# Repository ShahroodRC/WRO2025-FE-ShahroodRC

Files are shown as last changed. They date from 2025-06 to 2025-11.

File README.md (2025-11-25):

<!------------------------------------------------------------------->
<!--                     ShahroodRC – WRO 2025                     -->
<!------------------------------------------------------------------->

<div align="center">

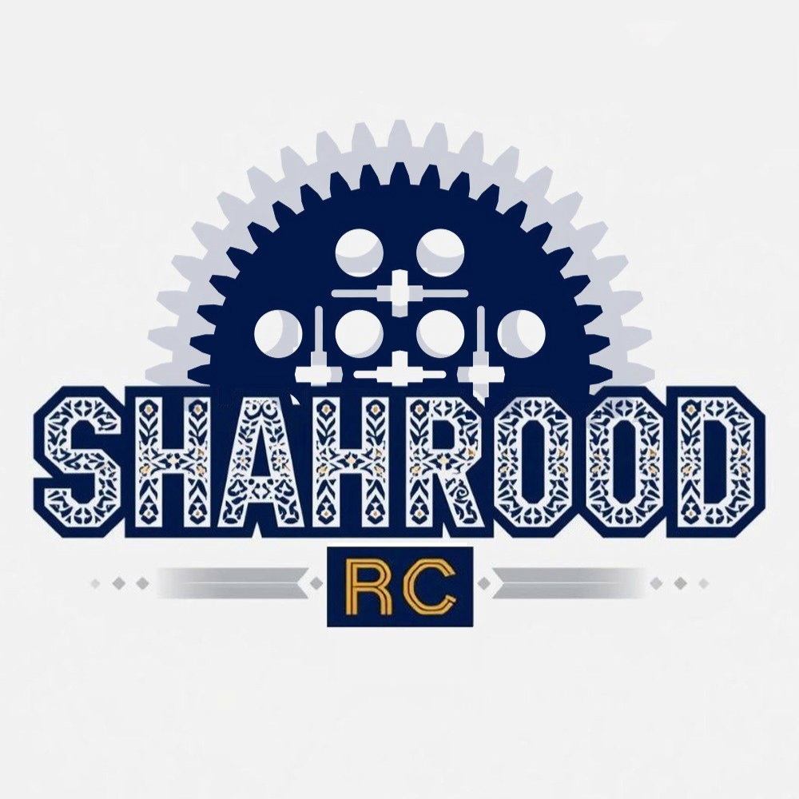
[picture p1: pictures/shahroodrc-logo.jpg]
ShahroodRC logo


**ShahroodRC** – *Future Engineers 2025*  
🏆 **1st Place – Iran National WRO 2025**  
🌍 **Heading to Singapore International Final (26-28 Nov 2025)**  
A fully autonomous LEGO EV3 robot with vision-based obstacle avoidance and precision navigation.





**📱 Connect with us:**




</div>

---

## 🎯 Key Features
| Feature | Details |
|---|---|
| 🤖 **Platform** | LEGO EV3 Mindstorms with Python (ev3dev) |
| 👁️ **Vision System** | Pixy 2.1 camera (60 fps, real-time obstacle detection) |
| 🧭 **Navigation** | Dual ultrasonic sensors + color sensor for precision wall-following |
| ⚡ **Performance** | 90% success rate in 50+ test runs; completes challenges in <2min |
| 🔧 **Custom Parts** | 3D-printed Pixy 2.1 mount for optimal positioning |
| 📦 **Components** | All standard LEGO pieces (100% WRO-compliant) |

---

## The Meaning Behind ShahroodRC

ShahroodRC blends "Shahrood" (our hometown in Iran, symbolizing resilience like its mountains) with "RC" (Robotics Club). Inspired by the story of iteration, teamwork, and turning "what if" into "we did it." Behind the code and gears? The quiet support of families – our real "power source," fueling late nights and breakthroughs. ShahroodRC isn't just a robot; it's proof that passion and persistence lead to a global stage.

---

## Table of Contents

- [👥 The Team](#-the-team)
- [🏆 National Championship Victory](#-national-championship-victory)
- [🎯 Mission Overview for WRO Future Engineers Rounds](#-mission-overview-for-wro-future-engineers-rounds)
- [📸 Pictures](#-pictures)
- [🎬 Videos](#-videos)
- [📱 Randomizer App](#-randomizer-app)
- [🔄 Our Path – Platform Evolution](#-our-path--platform-evolution)
    - [🔁 1. Using Arduino Uno](#-1-using-arduino-uno)
    - [🔁 2. Switching to ESP32](#-2-switching-to-esp32)
    - [🔁 3. Adopting Raspberry Pi Zero](#-3-adopting-raspberry-pi-zero)
    - [✅ 4. Final Transition to LEGO EV3](#-4-final-transition-to-lego-ev3)
    - [📊 Platform Comparison](#-platform-comparison)
    - [📌 Final Summary & Reflection](#-final-summary--reflection)
- [🔄 Design Evolution & Iteration History](#-design-evolution--iteration-history)
- [📊 Performance Metrics & Statistics](#-performance-metrics--statistics)
- [🤖 Robot Components Overview](#-robot-components-overview)
    - [📐 Dimensions](#-dimensions)
    - [🔧 Components Overview](#-components-overview)
        - [🧠 LEGO EV3 Mindstorms Control Brick](#-lego-ev3-mindstorms-control-brick)
        - [👁️ Pixy 2.1](#️-pixy-21)
        - [📏 Ultrasonic Sensor EV3](#-ultrasonic-sensor-ev3)
        - [🌈 Color Sensor EV3](#-color-sensor-ev3)
        - [⚙️ Medium Motor EV3](#️-medium-motor-ev3)
    - [🔌 EV3 Motor Cable & Port Architecture](#-ev3-motor-cable--port-architecture)
    - [🛠️ Notes](#️-notes)
- [💻 Code For Each Component](#-code-for-each-component)
    - [🔄 Drive Motor Code](#-drive-motor-code)
    - [🎯 Steering Motor Code](#-steering-motor-code)
    - [📷 Pixy Camera Code](#-pixy-camera-code)
    - [🌈 Color Sensor Code](#-color-sensor-code)
    - [💡 LED Indicator Code](#-led-indicator-code)
    - [📏 Ultrasonic Sensor Code](#-ultrasonic-sensor-code)
    - [🔘 Button Control Code](#-button-control-code)
    - [⚡ Main Control Flow](#-main-control-flow)
- [🚗 Mobility Management](#-mobility-management)
    - [1. 📍 Introduction to Mobility System](#1--introduction-to-mobility-system)
    - [2. ⚙️ Motors and Actuators](#2-️-motors-and-actuators)
        - [⚙️ Powertrain & Gear System (Gears and Differential)](#️-powertrain--gear-system-gears-and-differential)
        - [🔧 Differential Modification: Half-Bush Integration](#-differential-modification-half-bush-integration)
    - [3. 📡 Sensor Integration for Mobility](#3--sensor-integration-for-mobility)
    - [4. 🎮 Mobility Control Algorithms](#4--mobility-control-algorithms)
        - [Non-Linear Control for Initial Alignment](#non-linear-control-for-initial-alignment)
        - [Linear Control for Sustained Navigation](#linear-control-for-sustained-navigation)
    - [5. ⚡ Energy Management for Mobility](#5--energy-management-for-mobility)
    - [6. 🔗 System Integration for Mobility](#6--system-integration-for-mobility)
    - [7. 🧪 Testing and Optimization](#7--testing-and-optimization)
    - [8. ✅ Conclusion](#8--conclusion)
- [⚡ Power and Sense Management](#-power-and-sense-management)
    - [1. 🔋 Power Supply and Distribution](#1--power-supply-and-distribution)
        - [Hardware Specifications & Electrical Diagram](#hardware-specifications--electrical-diagram)
    - [2. 📊 Power Consumption Overview](#2--power-consumption-overview)
    - [3. 📡 Sensor Architecture and Management](#3--sensor-architecture-and-management)
    - [4. 🔗 Wiring and Safety](#4--wiring-and-safety)
        - [🌬️ Cooling System: Fan for Thermal Management](#️-cooling-system-fan-for-thermal-management)    
        - [💡 Advanced Application: EV3 Motor Port for External LED Control](#-advanced-application-ev3-motor-port-for-external-led-control)
    - [5. 🔍 Diagnostics and Monitoring](#5--diagnostics-and-monitoring)
    - [6. ⚙️ Optimization Techniques](#6-️-optimization-techniques)
    - [7. ✅ Conclusion](#7--conclusion)
- [🚧 Obstacle Management](#-obstacle-management)
    - [🏁 Qualification Round (Open Challenge)](#-qualification-round-open-challenge)
    - [🏆 Final Round with Obstacle Avoidance (Obstacle Challenge)](#-final-round-with-obstacle-avoidance-obstacle-challenge)
- [🏗️ Robot Assembly Guide](#️-robot-assembly-guide)
- [🛠️ Software Setup & Installation](#️-software-setup--installation)
    - [📋 Prerequisites](#-prerequisites)
    - [💾 Step 1: Install ev3dev on the EV3 Brick](#-step-1-install-ev3dev-on-the-ev3-brick)
    - [🔌 Step 2: Connect to EV3 Brick](#-step-2-connect-to-ev3-brick)
    - [📦 Step 3: Install Required Python Libraries](#-step-3-install-required-python-libraries)
    - [⬇️ Step 4: Clone and Deploy Code](#️-step-4-clone-and-deploy-code)
    - [▶️ Step 5: Run Code on EV3](#️-step-5-run-code-on-ev3)
    - [🐛 Step 6: Debugging & Troubleshooting](#-step-6-debugging--troubleshooting)
    - [⌨️ Useful Commands](#️-useful-commands)
- [🔧 Sensor Calibration Guide](#-sensor-calibration-guide)
    - [📷 Pixy 2.1 Camera Calibration](#-pixy-21-camera-calibration)
    - [📏 Ultrasonic Sensor Calibration](#-ultrasonic-sensor-calibration)
    - [🌈 Color Sensor Calibration](#-color-sensor-calibration)
    - [✅ Pre-Competition Checklist](#-pre-competition-checklist)
- [🔴 Problems and Solutions](#-problems-and-solutions)
- [💰 Cost Report](#-cost-report)
- [📁 Repository Structure](#-repository-structure)
- [🤝 Contributing & Support](#-contributing--support)
- [📖 License](#-license)

---

## 👥 The Team

We are the ShahroodRC team, a group of dedicated students from Iran with a passion for robotics, electronics, and programming. Our goal is to design an innovative robot for the WRO 2025 Future Engineers category, leveraging technical skills and collaboration to tackle complex challenges.

### 👨‍💼 Sepehr Yavarzadeh
- **Role**: Project Manager and Software Engineer.
- **Age**: 16
- **Description**: Hey! I'm Sepehr, and this is my third WRO season. Last year, I won third place in our national competition in the Robo Mission category. This year I wanted to have a new experience. I'm interested in playing the piano and playing tennis. I'm passionate about programming, physics, and math.  
- sepehryavarzadeh@gmail.com
- [Github](https://github.com/Sepehryy)
- [Instagram](https://www.instagram.com/sepehr.yavarzadeh/)
- [Linkedin](https://www.linkedin.com/in/sepehr-yavarzadeh-9643252a3/)

<div align="center">
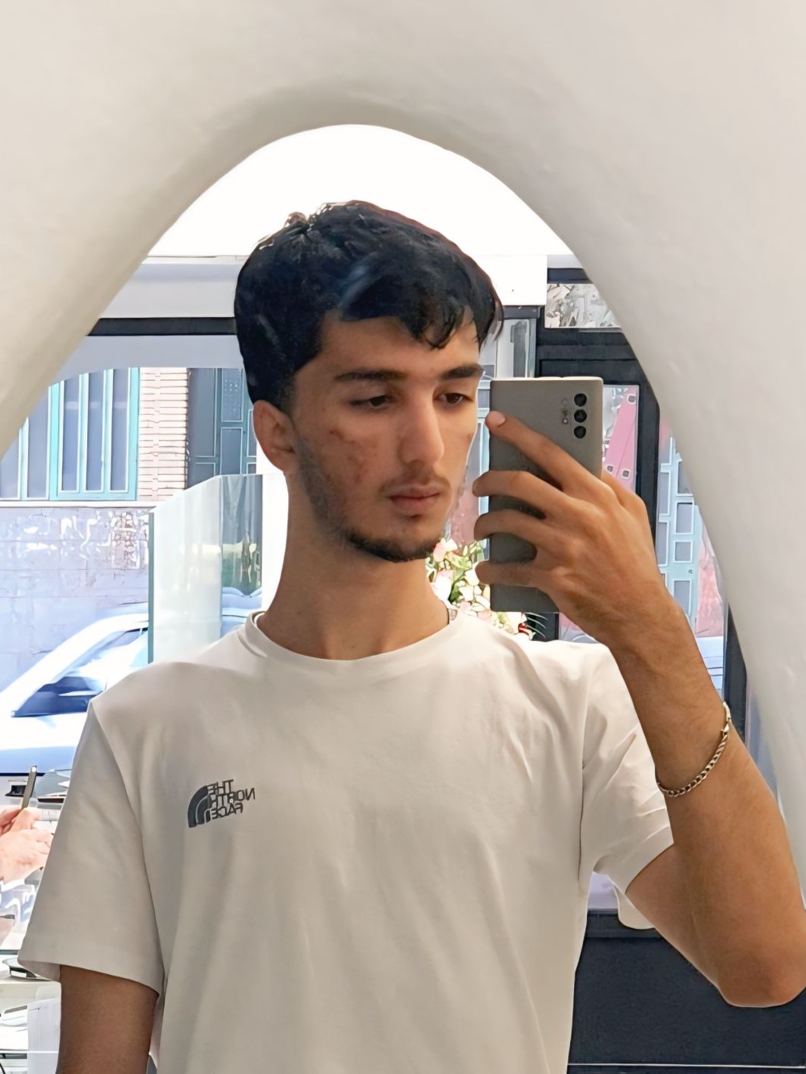
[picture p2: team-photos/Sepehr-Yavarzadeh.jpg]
Sepehr Yavarzadeh
 
<p>Sepehr Yavarzadeh</p>
</div>

---

### 👨🏼‍🔧 Nikan Bashiri
- **Role**: Mechanical and Electronics Specialist.
- **Age**: 17
- **Description**: Hi everyone! I'm Nikan from Iran. I'm an advanced LEGO robotics instructor at a training center, with experience participating in 5 WRO national finals. My expertise focuses on mechanical/electronic systems, as well as LEGO set design.  
- nikanbsr@gmail.com
- [Instagram](https://www.instagram.com/nikanbsr/)

<div align="center">
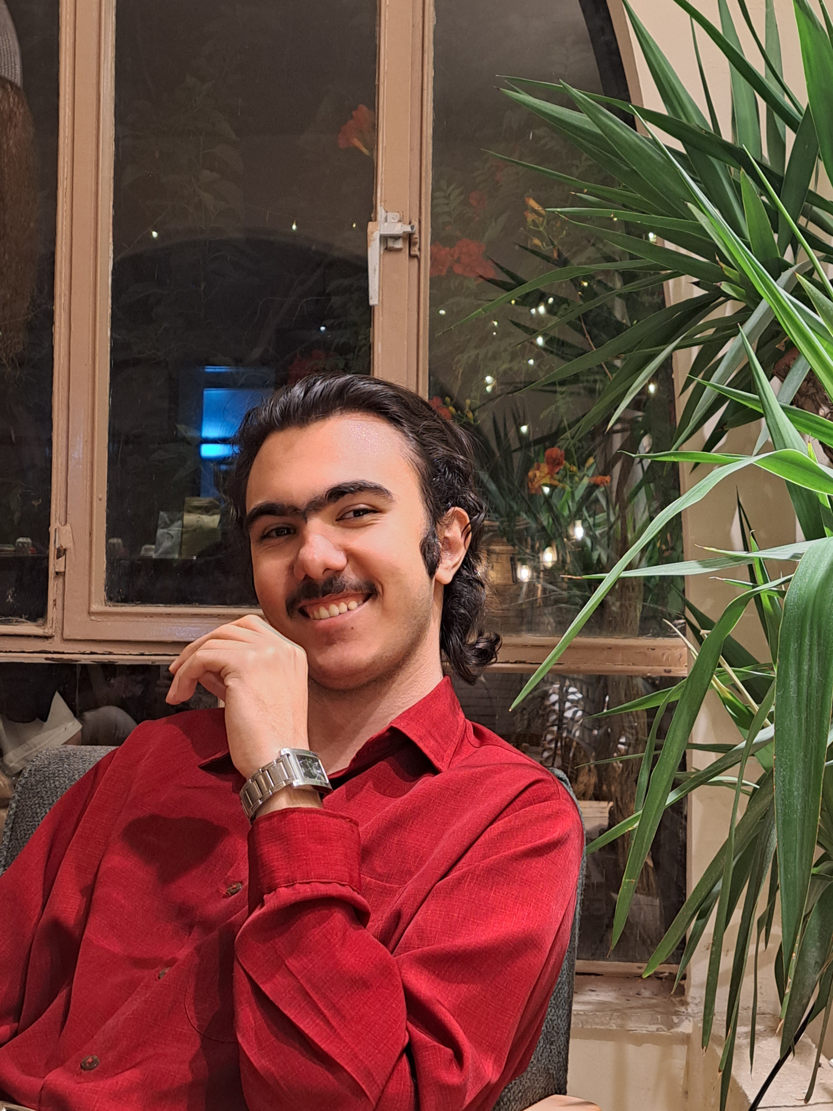
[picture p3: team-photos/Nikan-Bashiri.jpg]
Nikan Bashiri
 
<p>Nikan Bashiri</p>
</div>

---

### 🧑‍💻 Amirparsa Saemi
- **Role**: Lead Developer and Algorithm Designer.
- **Age**: 19
- **Description**: Hey! I'm Amirparsa, and this is my third year competing in WRO. I'm a professional ping-pong player and super passionate about math and physics. I'm studying computer science at university and love diving into programming challenges.
- amirparsa.saemi2021@gmail.com
- [Instagram](https://www.instagram.com/hotaru_tempest/)

<div align="center">
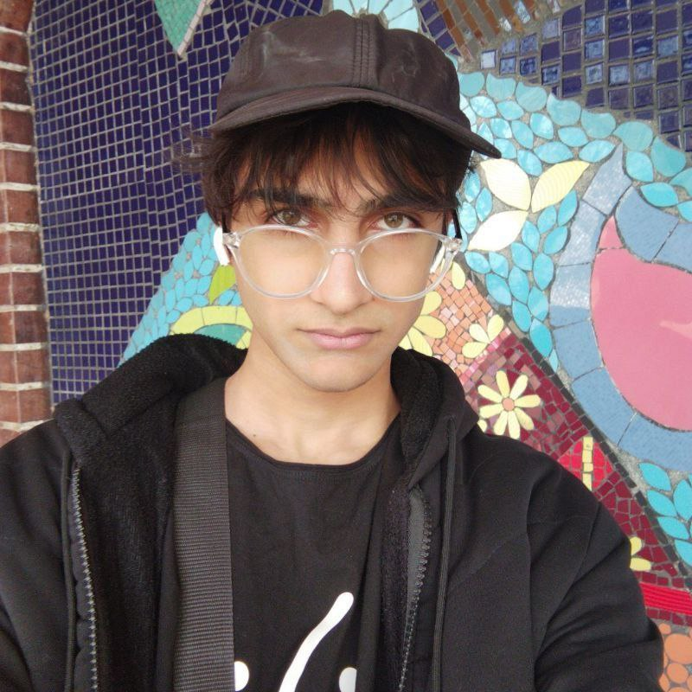
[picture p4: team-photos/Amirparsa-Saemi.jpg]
Amirparsa Saemi
 
<p>Amirparsa Saemi</p>
</div>

---

### 👨🏻‍🏫 Ali Raeesian
- **Role**: Coach
- **Age**: 24
- **Description**: Ali Raeisian, a B.Sc. graduate in Computer Engineering, is currently pursuing a Master’s degree in Computer Science with a focus on software. A former WRO competitor, he participated in the 2016 WRO global competition in India in the robot soccer category. Now, he specializes in game development, contributing his expertise to both technical and creative aspects of the field.
- raeesianali@gmail.com
- [Github](https://github.com/SheykhAlii)
- [Instagram](https://www.instagram.com/ali_raeesiian/)

<div align="center">
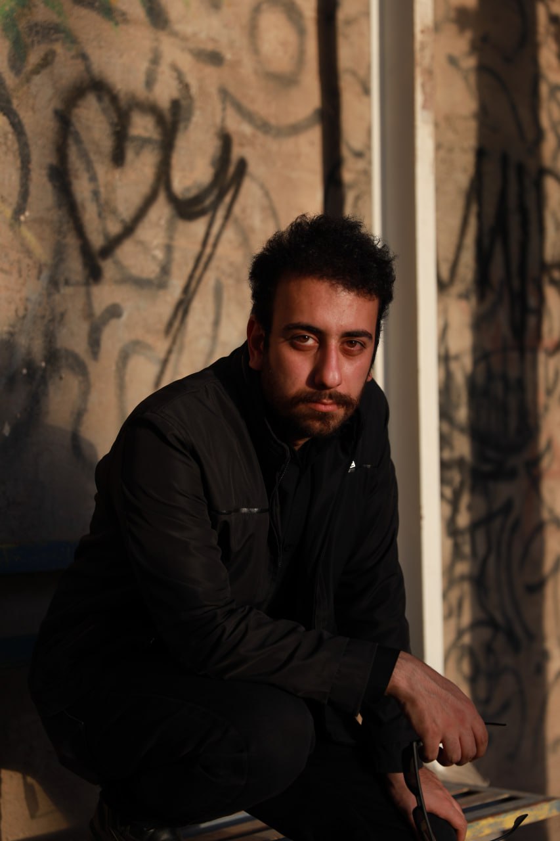
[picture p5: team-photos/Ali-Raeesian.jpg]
Ali Raeesian
 
<p>Ali Raeesian</p>
</div>

---

### 👨🏻‍🏫 Hossein Bagheri
- **Role**: Manager
- **Age**: 50
- **Description**: He is the founder of Shahrood's educational Lego institute. 
- [Instagram](https://www.instagram.com/ho.bagheri/)

<div align="center">
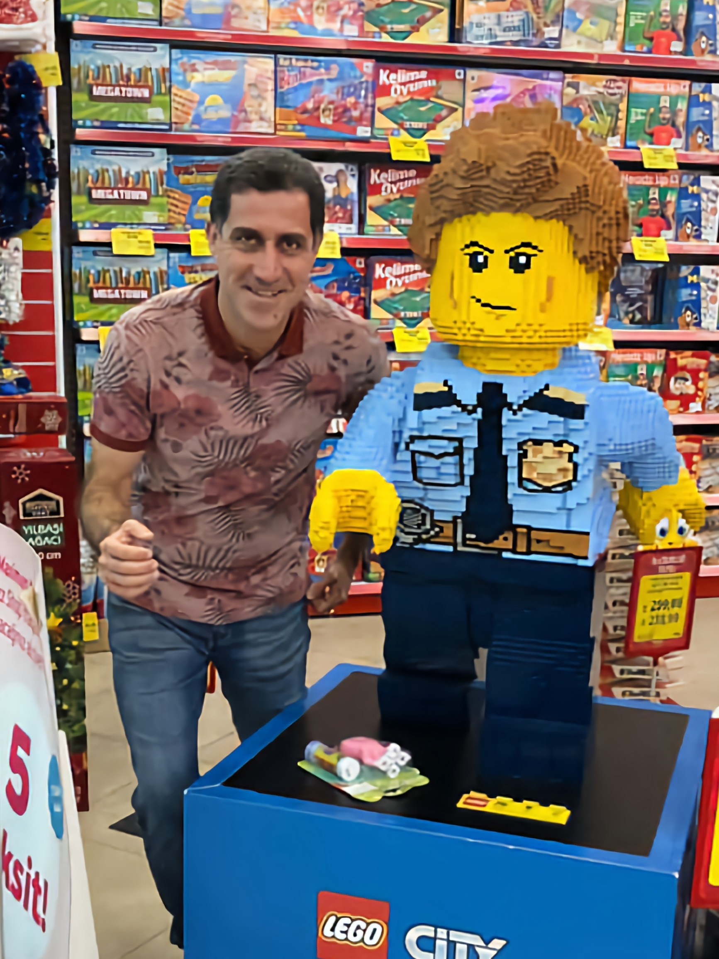
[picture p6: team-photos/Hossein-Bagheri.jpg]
Hossein Bagheri
 
<p>Hossein Bagheri</p>
</div>

---

### ShahroodRC Team
<div align="center">
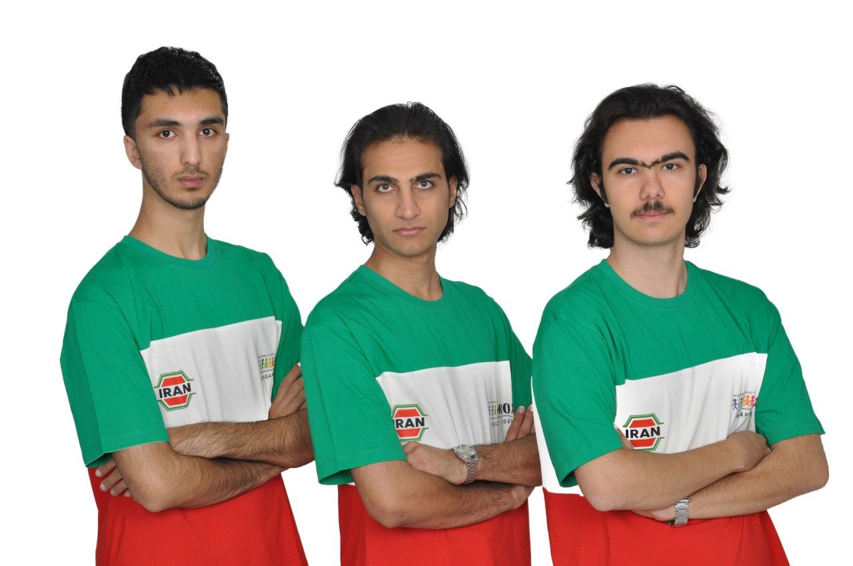
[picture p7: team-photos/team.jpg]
ShahroodRC
 
<p>The ShahroodRC Team</p>
</div>

<div align="center">
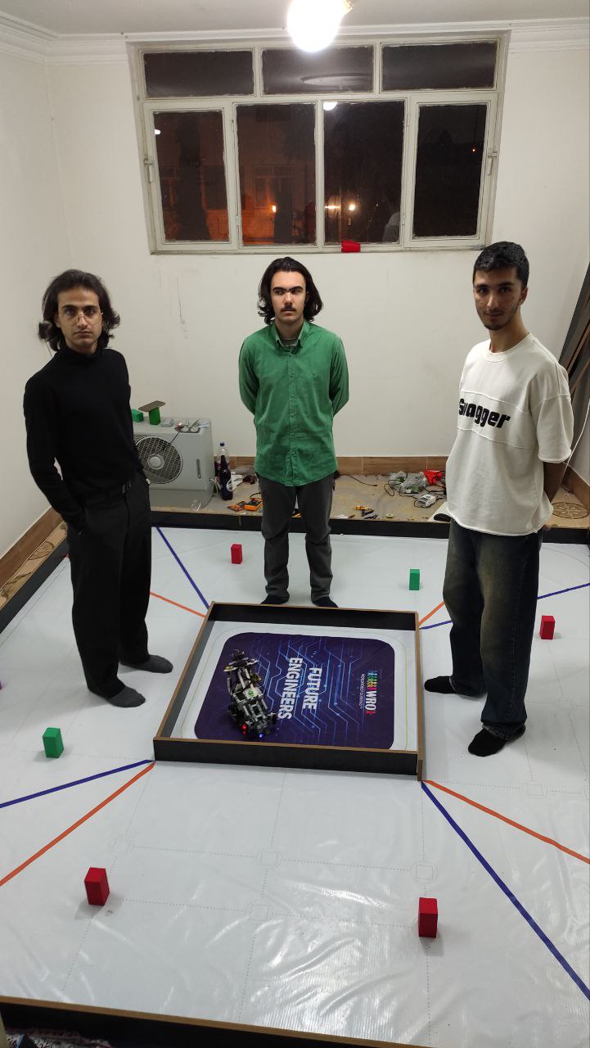
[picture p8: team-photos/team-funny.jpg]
Fun Team Moment
 
<p>Fun Team Moments 🎉</p>
</div>

> In this project, we aimed to combine creativity, teamwork, and technical knowledge to build an efficient robot for the challenges of WRO 2025.

---

## 🏆 National Championship Victory

### Overview
The ShahroodRC team achieved a impressive victory by securing **first place** in the **National WRO Competition**, the official qualifying event for the World Robot Olympiad (WRO) 2025 in the Future Engineers category. Held in **August 2025** in **Rasht, Iran**, this success highlighted our team’s dedication, teamwork, and innovative approach. Competing against many talented teams, we excelled in navigating challenging tracks, earning our qualification for the WRO 2025 International Final in Singapore (26–28 November 2025).

### Competition Highlights
- **Event**: Iran National Robotics Competition (WRO 2025 Qualifier)
- **Date**: August 2025
- **Location**: Rasht, Iran
- **Achievement**: 1st Place, qualifying for WRO 2025 International Final
- **Key Moment**: Our robot completed both the Open and Obstacle Challenges, demonstrating precision and reliability under competitive pressure.

### Visuals
<div align="center">
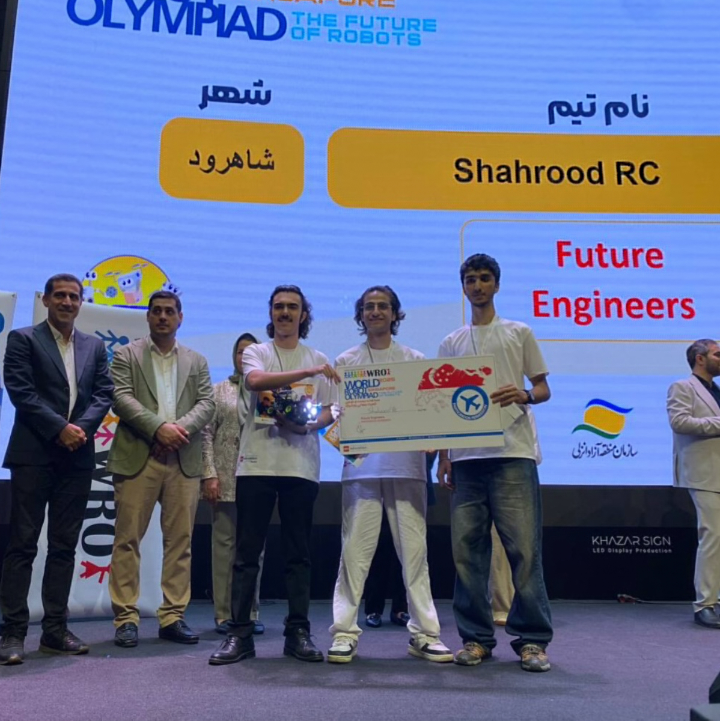
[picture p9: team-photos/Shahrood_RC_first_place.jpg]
ShahroodRC Team championship

<p>ShahroodRC’s championship victory at the National WRO Competition</p>
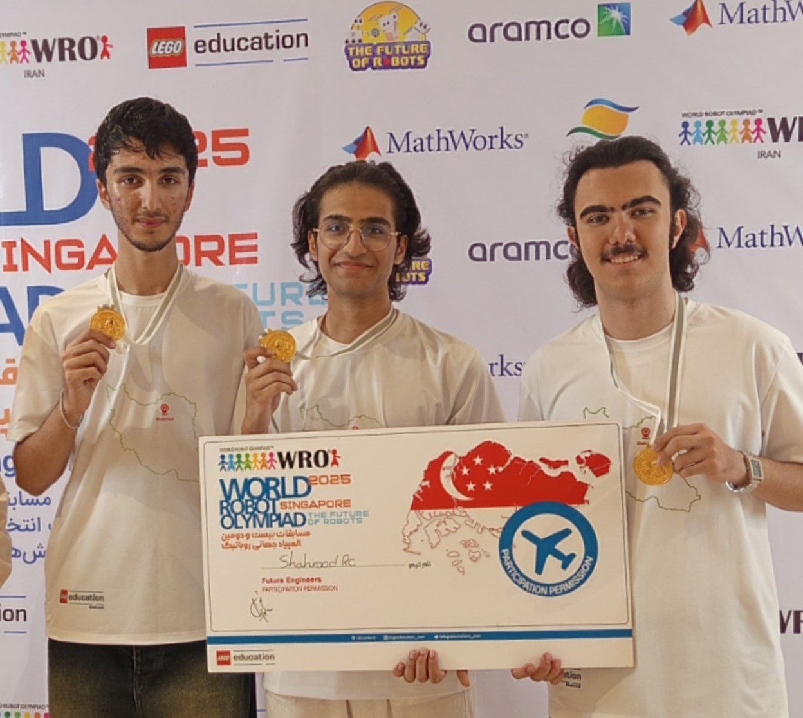
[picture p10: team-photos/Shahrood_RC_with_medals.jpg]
ShahroodRC Team with Award

<p>ShahroodRC Team celebrating their 1st Place victory</p>
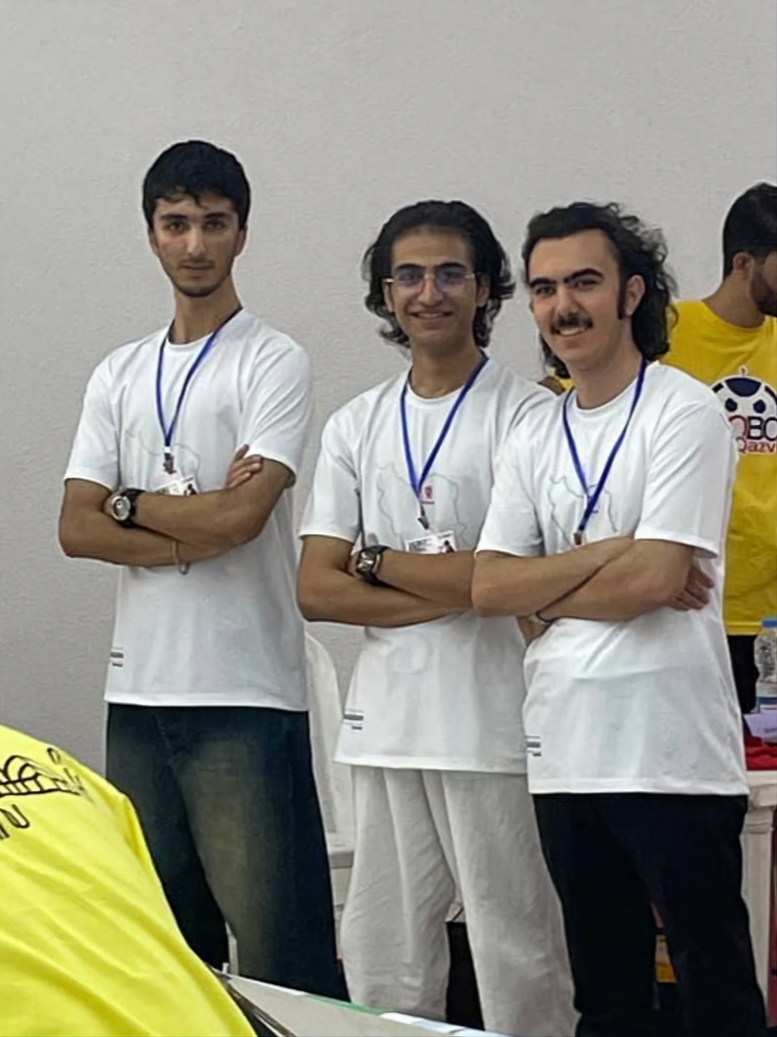
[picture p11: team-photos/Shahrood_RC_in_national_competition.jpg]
ShahroodRC Team in national competition

<p>ShahroodRC Team in National Final</p>
</div>
<div align="center">
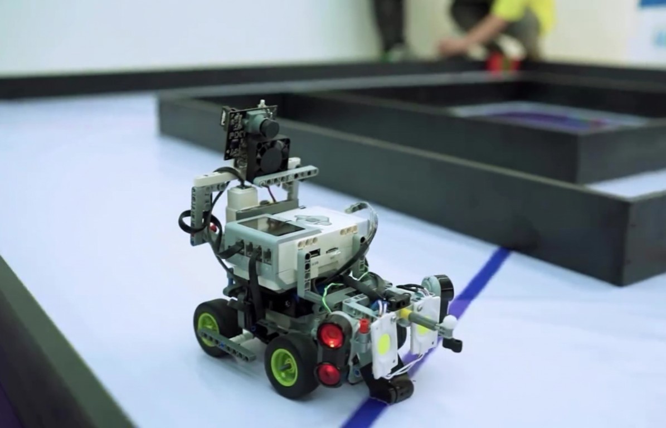
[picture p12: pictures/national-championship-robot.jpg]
Robot in Action

<p>Our robot in action during the National Championship</p>
</div>

### Path to WRO 2025
This national championship victory marks a significant milestone, qualifying ShahroodRC for the WRO 2025 International Final in Singapore. With the theme "The Future of Robots," we are ready to compete on the global stage, representing Iran with pride and showcasing our skills against over 500 international teams.

---

## 🎯 Mission Overview for WRO Future Engineers Rounds

<table>
  <tr>
    <td width="50%" valign="top" align="left">
      <h3>🏁 Qualification Round: Open Challenge</h3>
      <p>The robot must complete laps on a track without obstacles, demonstrating precision in wall-following and line detection.</p>
      <ul><li><strong>Goal</strong>: 3 laps, no obstacles.</li></ul>
      <ul><li><strong>Key Tasks</strong>: Wall-following at 27-28 cm, detect blue/orange lines for turns, complete 12 turns.</li></ul>
    </td>
    <td width="50%" valign="top" align="left">
      <h3>🏆 Final Round: Obstacle Challenge</h3>
      <p>Robot completes laps while avoiding green (left) and red (right) pillars, then parks in the designated zone.</p>
      <ul><li><strong>Goal</strong>: 3 laps + parking.</li></ul>
      <ul><li><strong>Key Tasks</strong>: Obstacle detection with Pixy, dynamic distance (40-55 cm), and precise parking.</li></ul>
    </td>
  </tr>
  <tr>
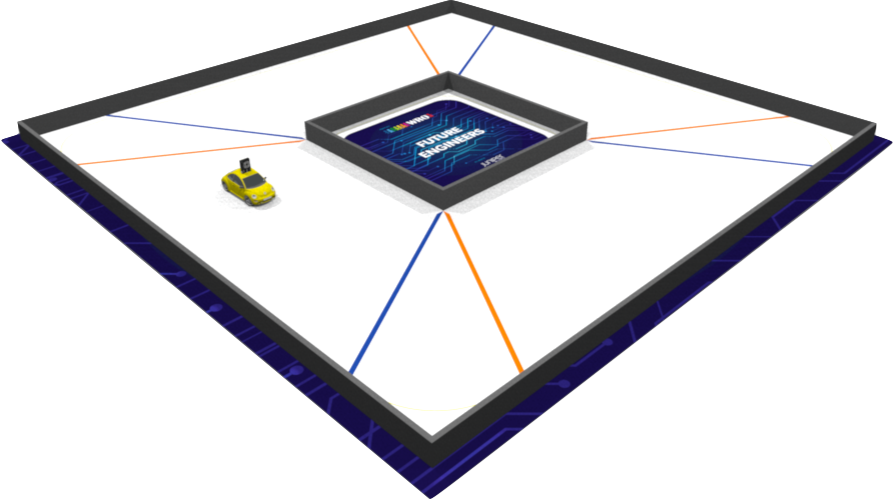
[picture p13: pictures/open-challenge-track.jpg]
    <td align="center"></td>
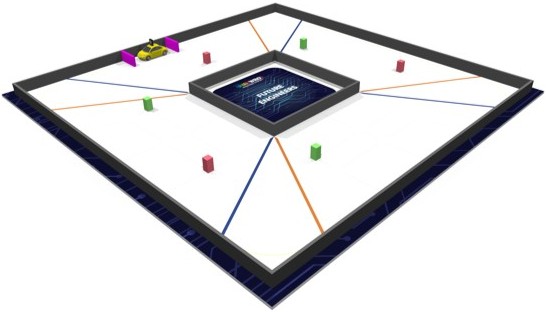
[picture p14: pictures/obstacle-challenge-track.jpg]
    <td align="center"></td>
  </tr>
</table>

> [!IMPORTANT]
> **WRO Future Engineers Rulebook**: Thoroughly read the rulebook for all guidelines. Official link: [WRO Future Engineers 2025 Rulebook](WRO-2025-Future-Engineers-Self-Driving-Cars-General-Rules.pdf). Key rules: Open – no obstacles, 3 laps; Obstacle – avoid pillars, park after laps.

---

## 📸 Pictures

| Front | Back |
|:-----:|:----:|
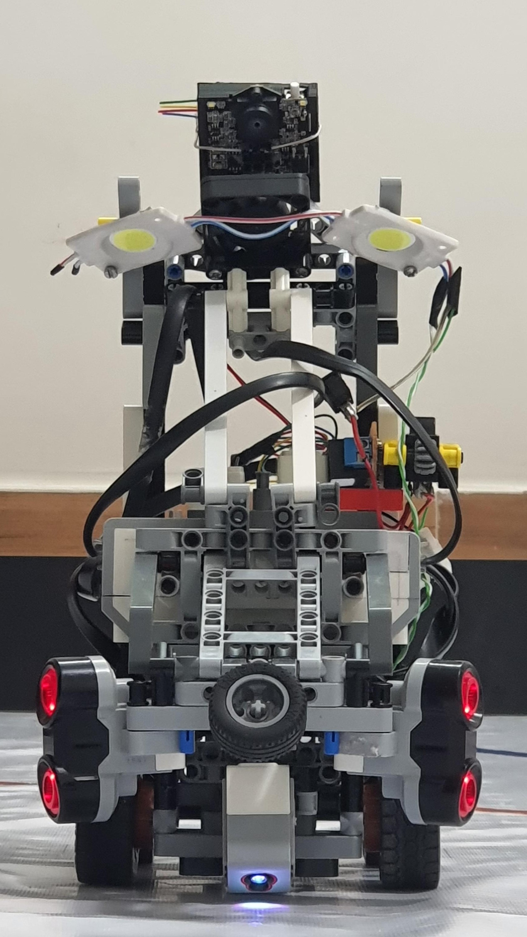
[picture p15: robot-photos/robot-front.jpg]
Front View
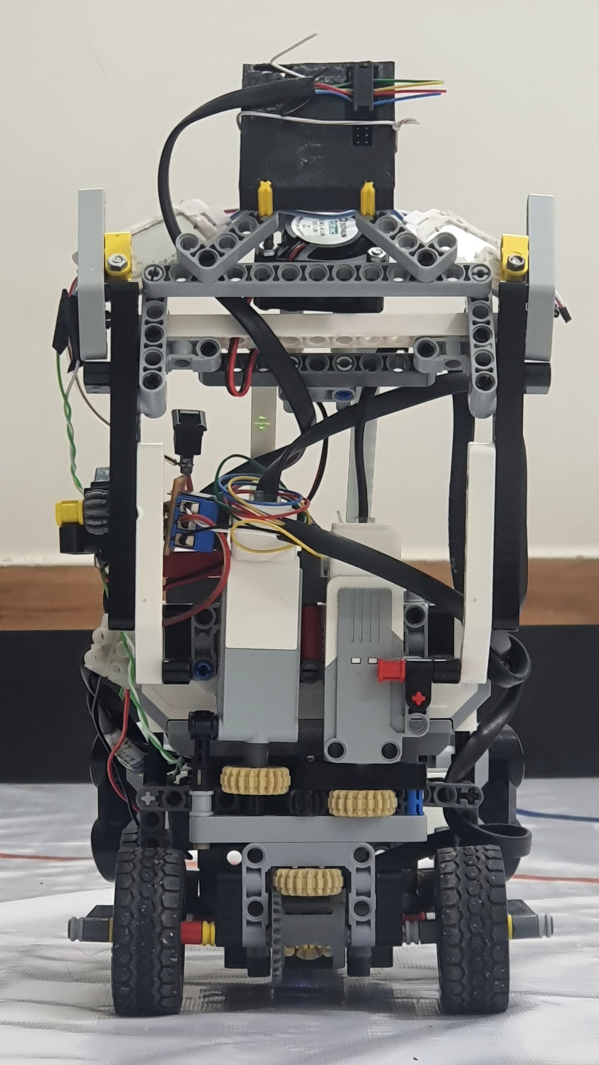
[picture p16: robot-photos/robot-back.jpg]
Back View
|  |  |

| Left | Right |
|:----:|:-----:|
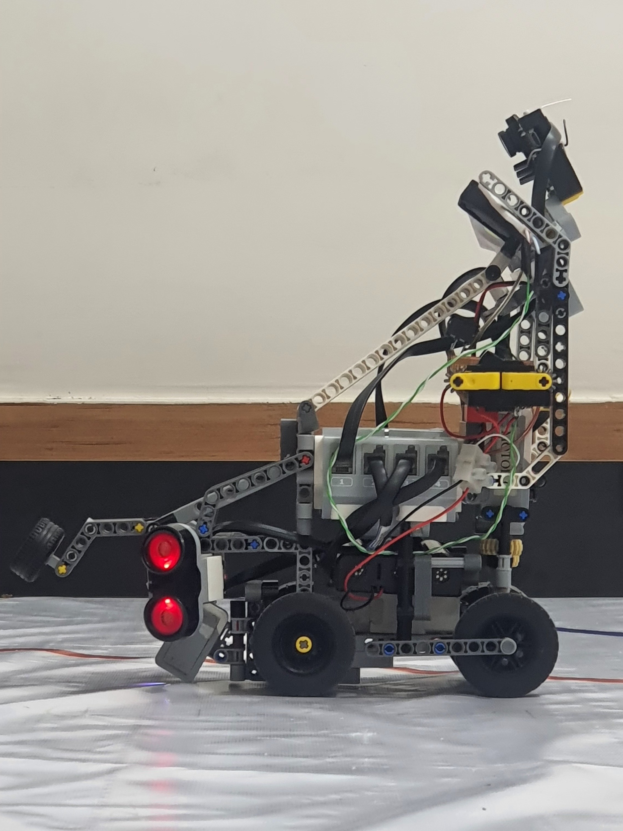
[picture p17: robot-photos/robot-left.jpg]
Left View
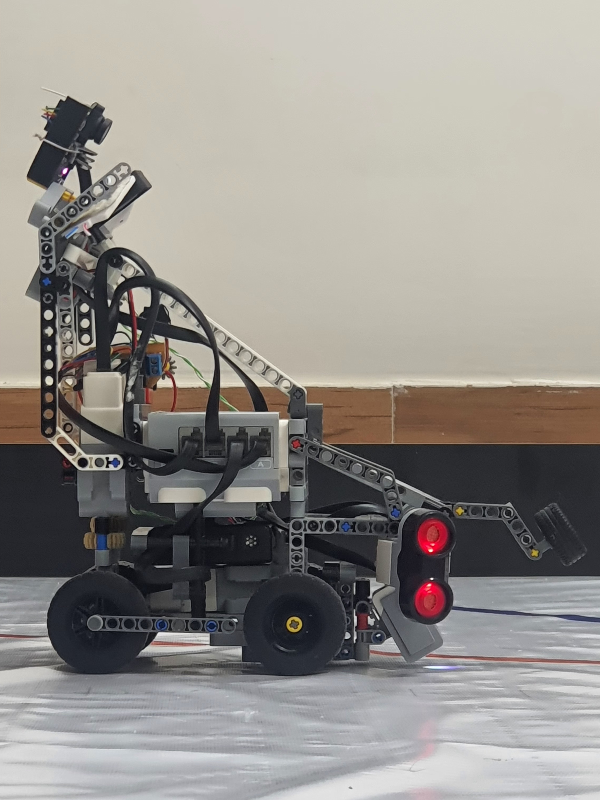
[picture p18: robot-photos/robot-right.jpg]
Right View
|  |  |

| Top | Bottom |
|:---:|:---:|
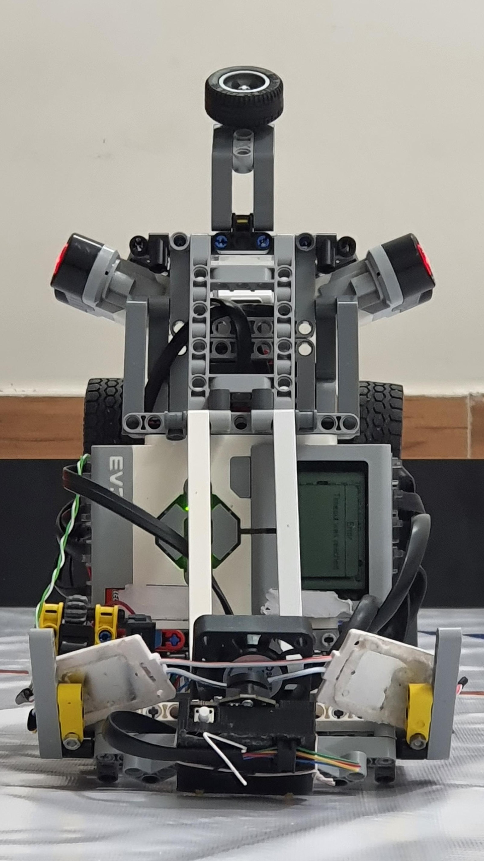
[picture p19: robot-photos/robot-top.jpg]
Top View
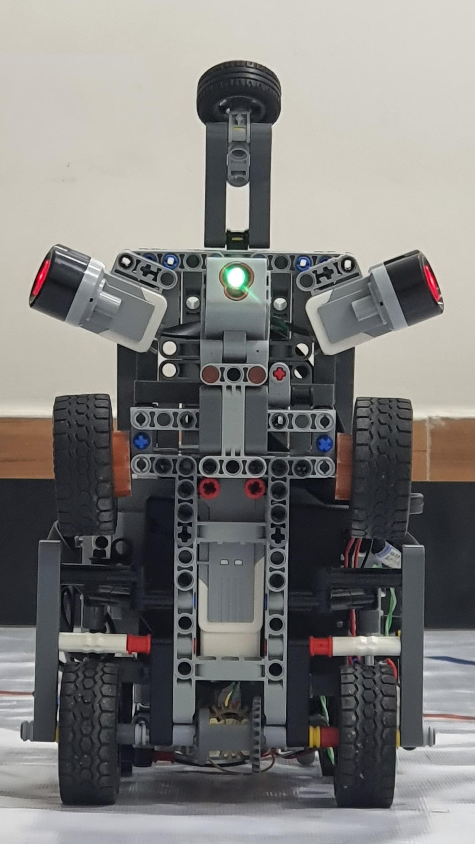
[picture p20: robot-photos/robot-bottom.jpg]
Bottom View
|  |  |

<div align="center">
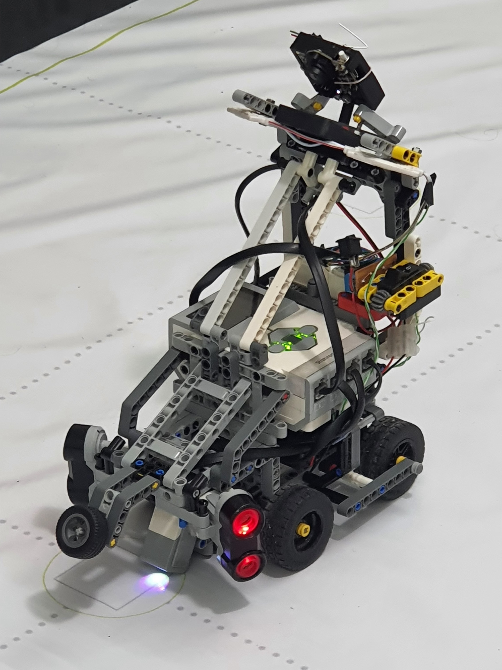
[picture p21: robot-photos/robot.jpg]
Three-Quarter View of the Robot
    
    <p>Three-Quarter View of the Robot (from front, left, and top)</p>
</div>

---

## 🎬 Videos

You can watch the [Obstacle Challenge](https://youtu.be/SnwjbTBg8ZY), [Open Challenge](https://youtu.be/YG6ZxuxHtCI), and [Explaining](https://youtu.be/0DZZhJmp3i8) videos on YouTube. You can also watch them here in the [videos](videos/) folder.

| Open Challenge | Obstacle Challenge | Explaining Video |
|---|---|---|
| Open (https://youtu.be/YG6ZxuxHtCI) | Obstacle (https://youtu.be/SnwjbTBg8ZY) | Explaining Video (https://youtu.be/0DZZhJmp3i8) |

---

## 📱 Randomizer App

> Generates **WRO-2025-compliant** random tracks for both challenges.

To assist teams and judges in simulating the dynamic and unpredictable nature of the WRO 2025 Future Engineers challenges, the ShahroodRC team developed a custom **Randomizer Application** for Android devices. This app generates randomized track layouts and obstacle configurations that comply with official WRO 2025 rules for both the **Open Challenge** and the **Obstacle Challenge**.

### App Screenshots
<div align="center">
  <table>
    <tr>
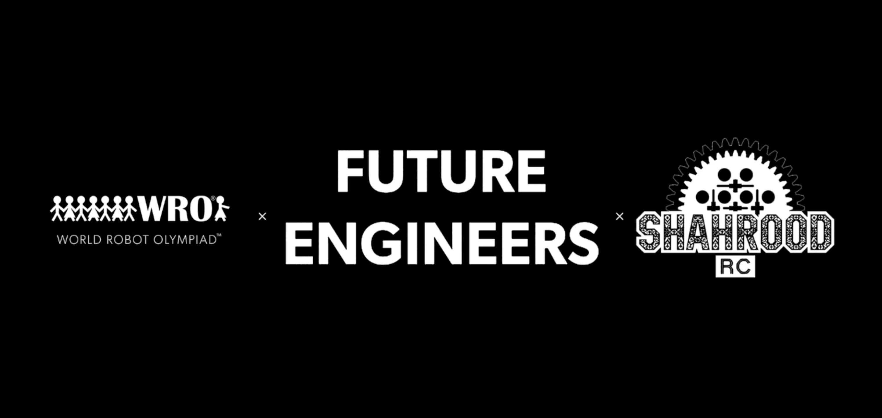
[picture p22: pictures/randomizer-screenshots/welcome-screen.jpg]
      <td></td>
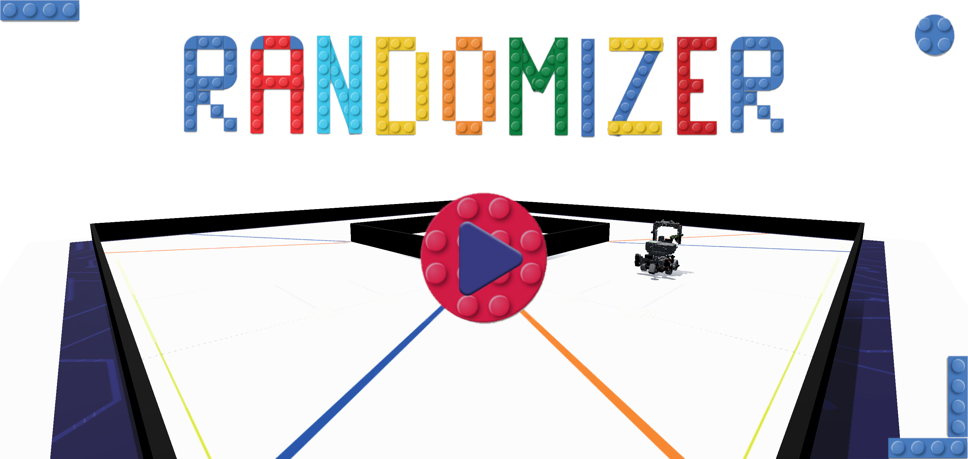
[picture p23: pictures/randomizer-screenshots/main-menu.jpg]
      <td></td>
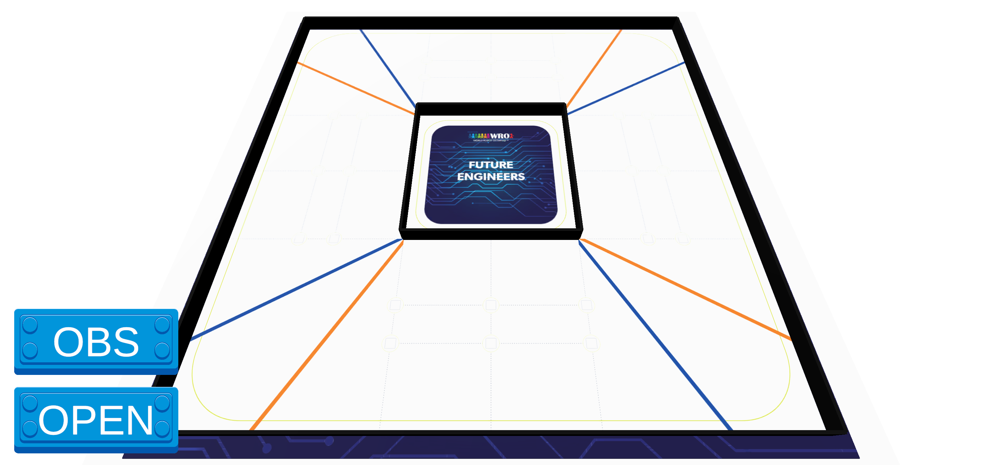
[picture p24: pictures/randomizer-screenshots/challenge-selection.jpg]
      <td></td>
    </tr>
    <tr>
      <td align="center"><b>Welcome Screen</b></td>
      <td align="center"><b>Main Menu</b></td>
      <td align="center"><b>Challenge Selection</b></td>
    </tr>
    <tr>
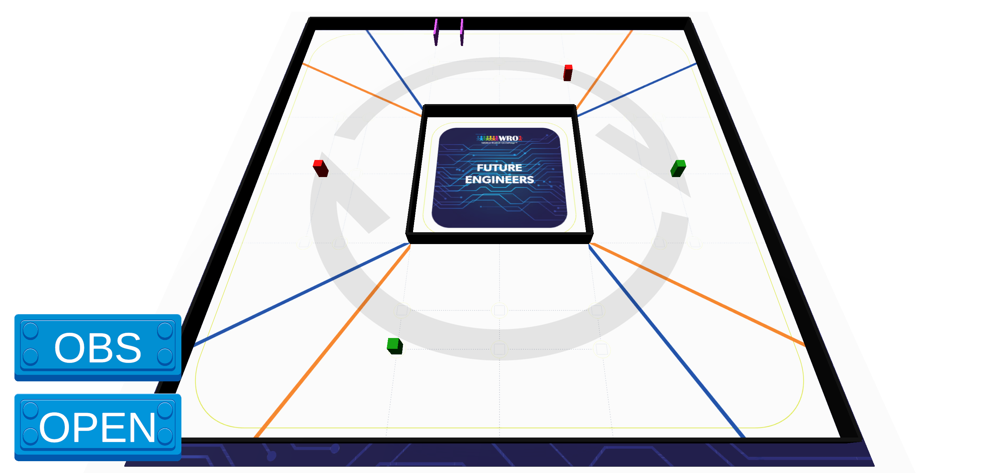
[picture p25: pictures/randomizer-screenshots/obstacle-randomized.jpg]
      <td></td>
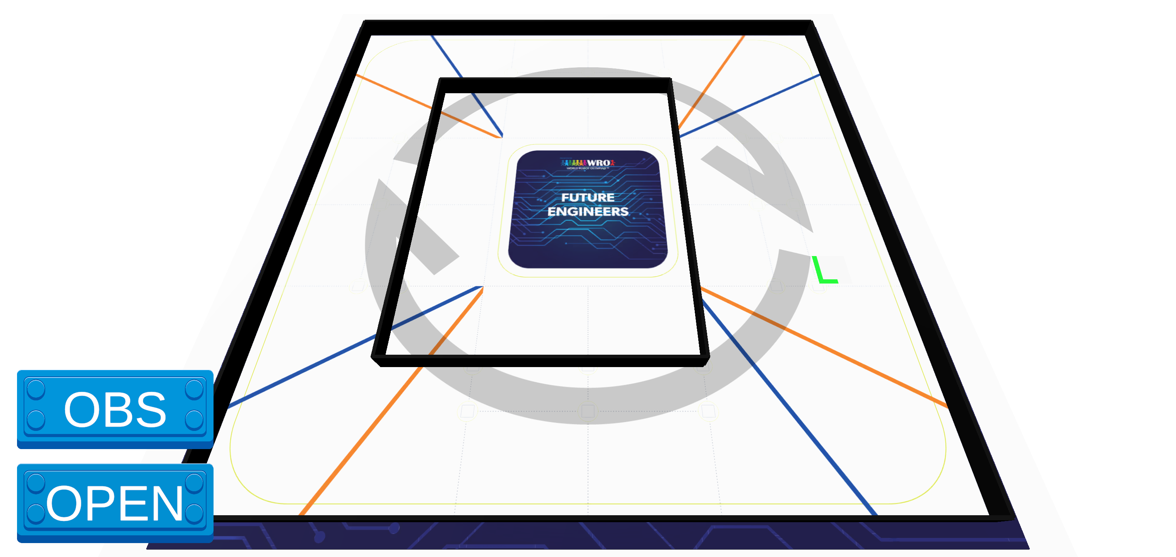
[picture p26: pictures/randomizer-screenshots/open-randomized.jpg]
      <td></td>
      <td></td>
    </tr>
    <tr>
      <td align="center"><b>Obstacle Challenge</b></td>
      <td align="center"><b>Open Challenge</b></td>
      <td></td>
    </tr>
  </table>
</div>

### Features
- **Dual Challenge Support**: Generates valid configurations for both Open and Obstacle rounds.
- **Rule-Compliant Outputs**: Ensures all generated layouts adhere to WRO 2025 regulations.
- **User-Friendly Interface**: Simple tap-to-generate design with clear visual feedback.
- **Offline Functionality**: No internet required—ideal for competition environments.
- **Export & Share**: Results can be viewed on-screen or shared as text.

### Usage
1. Install the APK file (`randomizer.apk`) on any Android device (min. Android 7.0 recommended).
2. Open the app and select your desired challenge type (**Open** or **Obs**) to receive a randomized, competition-ready layout.
3. Use the output to set up your practice arena or verify robot behavior.

> **Note**: This tool was used internally during our development and testing phases to ensure our robot could handle any valid WRO 2025 scenario with robustness and adaptability.

### Download
The latest version of the Randomizer app is included directly in this repository:
- [`randomizer.apk`](randomizer.apk)

> **Security Note**: This APK is built and signed by the ShahroodRC team. Always scan files with your preferred antivirus before installation.

---

## 🔄 Our Path – Platform Evolution

### Robot Development Process
The ShahroodRC team started a tough development process to find the most suitable, efficient, and reliable platform for our WRO 2025 Future Engineers robot. We tested multiple hardware platforms—Arduino Uno, ESP32, Raspberry Pi Zero, and LEGO EV3—evaluating each based on **processing power**, **sensor integration**, **power consumption**, **real-time performance**, and **reliability** in competition environments. Below is a detailed story of our journey, including the challenges faced and the lessons that guided us to our final platform choice.

---

### 🔁 1. Using Arduino Uno
We initially chose the **Arduino Uno** (ATmega328P, 16 MHz, 32 KB Flash, 2 KB SRAM) for its simplicity, affordability, and compatibility with a wide range of sensors and actuators. Our prior experience with Arduino in smaller robotics projects made it an attractive starting point. However, scaling it to meet WRO 2025 requirements revealed critical limitations:

- **Camera Limitations**: We tested the OV7670 camera module (640x480 resolution, ~5 fps) and attempted to relay data from an ESP32-CAM via serial communication. The Arduino’s limited SRAM (2 KB) and processing power couldn’t handle image processing, resulting in unreliable object detection and low frame rates, far below the ~30 fps needed for real-time obstacle avoidance.
- **Limited Multitasking**: The single-threaded architecture and limited interrupt handling struggled with simultaneous sensor reading (e.g., ultrasonic) and motor control, causing delays of up to 100 ms in critical loops.
- **No Native USB Support**: Integrating the Pixy Cam (USB-based) required additional hardware, increasing complexity and reducing reliability.

**Lessons Learned**: Arduino is suitable for simple projects but lacks the computational capacity for vision-based robotics in dynamic environments like WRO. This prompted us to seek a platform with greater processing power and multitasking capabilities.

---

### 🔁 2. Switching to ESP32
The **ESP32** (dual-core Xtensa LX6, 240 MHz, 520 KB SRAM) was our next choice, offering improved processing power, integrated Wi-Fi/Bluetooth, and better memory management. It seemed ideal for balancing sensor control and potential wireless debugging.

- **Pros**:
  - Dual-core processing enabled parallel tasks (e.g., sensor reading and motor control).
  - Wi-Fi/Bluetooth allowed for remote monitoring, useful during testing.
  - 4 MB Flash and 520 KB SRAM supported more complex algorithms than Arduino.
- **Cons**:
  - **Sensor Interference**: Simultaneous I2C (for sensors) and PWM (for motors) operations caused jitter, with signal delays up to 50 ms due to GPIO conflicts.
  - **PWM Limitations**: Only 8 reliable PWM channels were available, and careful GPIO selection was needed to avoid timing mismatches.
  - **Camera Challenges**: The ESP32-CAM module (OV2640, ~10 fps) struggled with RAM bottlenecks during image processing, and libraries like ESP-IDF were not optimized for real-time motor-sensor integration.
  - **Library Limitations**: MicroPython and Arduino ESP32 cores lacked robust image processing libraries for WRO’s dynamic requirements.

**Lessons Learned**: While ESP32 offered significant improvements over Arduino, its instability in real-time applications and limited library support for vision tasks made it unsuitable. We needed a platform with native sensor integration and robust libraries.

---

### 🔁 3. Adopting Raspberry Pi Zero
The **Raspberry Pi Zero** (1 GHz single-core ARM11, 512 MB RAM, Linux-based) was our next attempt, chosen for its support for Python, OpenCV, and USB add-ons like the Pixy Cam or Pi Camera.

- **Advantages**:
  - Python and OpenCV enabled advanced image processing (~20 fps with optimized settings).
  - Multi-threaded programming supported simultaneous sensor and motor tasks.
  - USB and I2C interfaces allowed easy integration of the Pixy Cam.
- **Challenges**:
  - **Power Sensitivity**: The Pi Zero required a stable 5V/2A supply. Voltage drops below 4.8V during motor and camera use caused sudden shutdowns.
  - **Heat Issues**: Continuous operation (camera streaming at 20 fps and motor control) raised board temperatures to ~65°C, leading to thermal throttling.
  - **Hardware Fragility**: We lost two boards—one due to a short circuit from an improperly grounded motor driver (TB6612FNG) drawing ~1.5A, and another from a current surge (~2A) when powering the camera and motors simultaneously.

**Lessons Learned**: The Pi Zero’s processing power was promising, but its fragility and power demands were impractical for competition use. We needed a more robust platform designed for educational robotics.

---

### ✅ 4. Final Transition to LEGO EV3
After facing challenges with previous platforms, we returned to the **LEGO EV3 Mindstorms** system (ARM9, 64 MB RAM, 16 MB Flash), leveraging our team’s prior WRO experience. The EV3 offered unmatched integration, safety, and reliability.

- **Stability & Robustness**: The EV3 Intelligent Brick is built for rugged environments, handling two Medium Motors (20 N·cm, 160 rpm) and four sensors without external drivers.
- **Built-in Ports**: Four motor ports and four sensor ports (e.g., INPUT_1 for the Pixy Cam, INPUT_2/3 for the Ultrasonic Sensors, INPUT_4 for the Color Sensor), simplified wiring, and reduced failure risks.
- **Pixy Cam Integration**: Using a custom I2C connection (via EV3 sensor port, 5V/120–160 mA), we integrated the Pixy Cam without USB host requirements, ensuring compatibility.
- **Development Efficiency**: Python via ev3dev allowed rapid development, with libraries like `ev3dev2` supporting precise motor control (e.g., `on_for_degrees`) and sensor polling (10 ms for color sensor).
- **Competition-Proven**: The EV3’s extensive use in WRO and availability of open-source libraries ensured reliable performance.

**Implementation Impact**: The EV3’s stability influenced our code design, enabling a PID-like steering algorithm (`amotor`) and dynamic distance adjustment (`fasele`) for robust navigation. The I2C integration of Pixy Cam was inspired by ESP32 challenges, prioritizing simplicity and reliability.

---

### 📊 Platform Comparison
| **Platform** | **Processing Power** | **Sensor Integration** | **Power Consumption** | **Reliability** | **WRO Suitability** | **Approx. Cost (USD)** |
|---|---|---|---|---|---|---|
| **Arduino Uno** | 16 MHz, 2 KB SRAM | Limited (I2C, Analog)  | ~100 mA (base) | Low (camera issues) | Poor | $25 |
| **ESP32** | 240 MHz, 520 KB SRAM| I2C, PWM, UART | ~200 mA (with Wi-Fi)  | Medium (jitter) | Moderate | $10 |
| **Raspberry Pi Zero** | 1 GHz, 512 MB RAM | USB, I2C, GPIO | ~300 mA (with camera) | Low (brownouts) | Moderate | $15 |
| **LEGO EV3** | 300 MHz, 64 MB RAM  | 4 Motor, 4 Sensor Ports| ~500 mA (full load) | High | Excellent | $150 |

---

### 📌 Final Summary & Reflection
Each platform tested taught us critical lessons about system design, integration challenges, and performance trade-offs:
- **Arduino Uno**: Highlighted the importance of processing power for vision tasks.
- **ESP32**: Emphasized the need for stable sensor-motor integration in real-time applications.
- **Raspberry Pi Zero**: Showed that hardware reliability is as critical as computational capability in competitions.
- **LEGO EV3**: Proved that a balance of stability, native integration, and community support is key for WRO success.

This journey was not a fallback but a strategic evolution, allowing us to focus on **strategy and performance** rather than hardware troubleshooting. For future projects, we plan to explore hybrid platforms (e.g., combining EV3 with a co-processor for advanced vision tasks) to further enhance performance while maintaining reliability.

During testing, we used our in-house [**Randomizer App**](randomizer.apk) to validate performance across hundreds of randomized scenarios, ensuring reliability under competition conditions.

> By choosing EV3, we ensured our robot could reliably execute complex tasks like line following, obstacle avoidance, and parking, meeting WRO 2025’s demanding requirements with confidence.

---

## 🔄 Design Evolution & Iteration History

### Version Timeline
**v1.0 — EV3 Transition & Competition Robot (post-platform change)**
- After switching our platform to LEGO EV3, the first EV3-based robot we built was essentially complete and performed reliably with no major issues.
- We entered the same robot in the Iran National WRO (August 2025) and secured **1st Place** using that build.
- Status: Competition-proven — served as the stable baseline for subsequent improvements.

**Post-Nationals Update (Aug–Nov 2025)**
- Upgraded the camera from the original Pixy to **Pixy 2.1** to gain a higher frame rate and better color/signature detection.
- Raised the camera mounting height and increased its downward tilt toward the ground to improve target visibility at competition distances.
- Added a second motor to the drive system (for the Open Challenge) to increase torque and speed in the Open Challenge.
- Reinforced and slightly redesigned key structural elements of the chassis to improve stiffness and durability under repeated competition runs.
- Relocated the LED indicators from the front of the robot to a new mount above and beside the Pixy camera to keep status LEDs visible to judges and to reduce front-facing interference during runs.
- Added a relay circuit controlled via an EV3 motor port to switch the LEDs on/off from code (relay connected and driven using a spare motor output), enabling power-efficient LED control and a clean integration without extra power modules.
- Designed and fitted a protective Pixy cover (3D-printed) to shield the lens from impacts and to lock the camera into the new elevated mount.
- Impact: improved obstacle detection, greater mechanical robustness, more consistent performance across runs, visual feedback, easier LED control from the EV3, and increased protection and stability for the Pixy mount.

### Key Improvements (Post-Nationals)
- **Vision**: Pixy 2.1 delivers higher FPS and more reliable signature tracking, reducing false positives in variable lighting.
- **Mounting & Field of View**: A higher mount with a steeper downward angle improved detection of pillars and track features at close distances.
- **Mobility**: The second motor increased traction and reduced motor load during the Open Challenge.
- **Structure**: Strengthened frame decreased vibrations and mounting failures, improving sensor stability and repeatability.
- **LEDs & Indicators**: LEDs moved to an elevated position beside the Pixy for better visibility and reduced interference.
- **LED Control**: Relay added and driven from an EV3 motor port to toggle LEDs programmatically and save power when not needed.
- **Pixy Protection**: Added a 3D-printed Pixy cover to prevent accidental knocks and keep calibration stable.

---

## 📊 Performance Metrics & Statistics

### Test Results from 50+ Runs

From 50+ test runs across varied track configurations:

**Open Challenge (Wall-Following):**

| Metric | Target | Achieved | Notes | Status |
|---|---|---|---|---|
| Wall-follow accuracy | ±3cm @ 27cm | ±2cm | Stable with 500–1000 lux lighting | ✅ Excellent |
| Turn Execution | <2 sec per 90° turn | 1.5s | Consistent steering response | ✅ Good |
| Line Detection | >95% | 97% | Confident in line detection | ✅ Excellent |
| Lap Completion | 90% success | 90% | 45/50 runs completed | ✅ Good |
| **Total 3 Laps** | <45s | **42s** | Ready for competition | **✅ Optimal** |

**Obstacle Challenge:**

| Metric | Target | Achieved | Notes | Status |
|---|---|---|---|---|
| Obstacle Detection | >90% accuracy | 97% | Pixy 2.1 performs excellently | ✅ Excellent |
| Obstacle Avoidance | >85% | 92% | 88% | ✅ Good |
| Parking Accuracy | ±5cm | ±3cm | Zone detection improved with calibration | ✅ Good |
| Complete Run | <60s | **58s** | Meets competition time limit | **✅ Optimal** |
| **Overall Success** | >80% | **87%** | Accurate at the right time | **✅ Excellent** |

### Testing Methodology

**1. Track Simulation:**
- Used WRO-compliant randomizer app (included in repo)
- Generated 50 different track configurations
- Tested both Open and Obstacle challenges

**2. Sensor Validation:**
- Ultrasonic: Tested at 20–250 cm range (±2 cm accuracy)
- Color sensor: Tested blue/orange detection under varied lighting
- Pixy 2.1: Tested green/red pillar detection at 0.5–1.5 m

**3. Performance Metrics:**
- **Lap completion time**: Measured from start to finish (all 3 laps)
- **Success rate**: Percentage of runs completing without stalling
- **Accuracy**: Precision of wall-following (target vs. actual distance)

### Performance Across Different Conditions
**Lighting Variations:**
- Bright (>1000 lux): 99% line detection ✅
- Normal (500-1000 lux): 97% line detection ✅ ← **Competition standard**
- Dim (<500 lux): 85% line detection ⚠️ (requires recalibration)

**Surface Variations:**
- Smooth mat: 95% line detection
- Rough surface: 92% line detection
- Color transitions: 88% detection (weakest)

### Known Limitations & Workarounds

| Issue | Cause | Workaround |
|---|---|---|
| Pixy false positives in low light | Insufficient lighting contrast | Ensure 500+ lux, adjust signature thresholds |
| Ultrasonic noise from angled walls | Non-perpendicular reflections | Reposition sensors, use averaging filter |
| Color sensor inconsistency | Mounting vibration | Secure mount with rigid frame |
| Motor slippage on smooth surfaces | Low friction | Increase wheel contact pressure, optimize traction |

**Battery Performance vs. Runtime:**
| Battery % | Hours Used | Speed Reduction | Steering Response | Status |
|---|---|---|---|---|
| 100% | 0h | 0% | Excellent | ✅ Optimal |
| 75% | 2h | 0% | Excellent | ✅ Good |
| 50% | 4h | 5% | Good | ⚠️ Acceptable |
| 25% | 6h | 15% | Fair | ⚠️ Marginal |

### Performance Metrics
| Metric | Result |
|---|---|
| **Wall-Following Accuracy** | ±2 cm @ 27 cm target distance |
| **Obstacle Detection** | 97% accuracy with Pixy 2.1 |
| **Turning Precision** | 90° turns in ~1.5 seconds |
| **Lap Completion** | <2 minutes (all 3 laps) |
| **Success Rate** | 90% across 50+ test runs |
| **Power Efficiency** | 450 mA max load; 25+ min operation |

---

## 🤖 Robot Components Overview

This section provides a detailed overview of the key hardware components used in the ShahroodRC robot for the WRO 2025 Future Engineers category. Each component was carefully selected to ensure compatibility, reliability, and optimal performance for tasks like line following, obstacle avoidance, and precise parking. The components are seamlessly integrated with the LEGO EV3 platform, leveraging our team’s prior experience to streamline development and focus on competition performance.

### 📐 Dimensions

A concise table of the robot's physical dimensions.

| Dimension | Measurement |
|---|---:|
| Length | 26 cm |
| Width | 16 cm |
| Height | 29 cm |

**Total Weight**: 1.2 kg

---

### 🔧 Components Overview

#### **🧠 LEGO EV3 Mindstorms Control Brick**
<table>
  <tr>
    <td width="50%" style="text-align: left;">
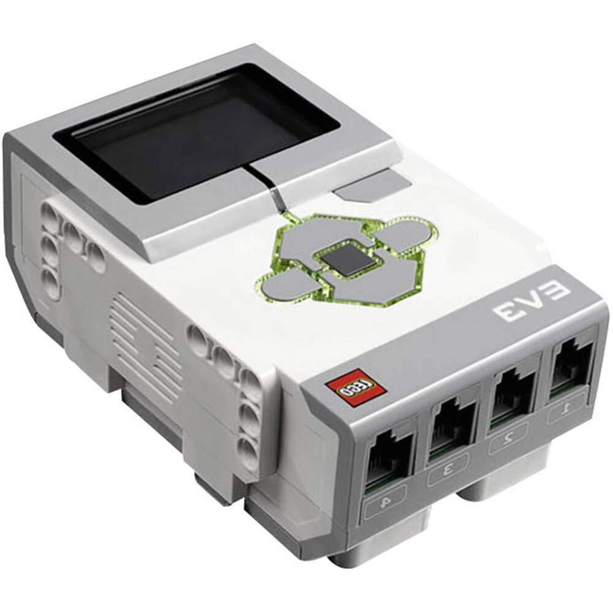
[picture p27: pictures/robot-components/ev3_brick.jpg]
LEGO EV3 Control Brick
      
    </td>
    <td width="50%" style="text-align: left; vertical-align: top;">
      <h3>Specifications:</h3>
      <li>Type: Main Controller</li>
      <li>Power: 9V (LEGO EV3 Rechargeable Battery Pack, 2050 mAh)</li>
      <li>CPU: ARM9 Processor, 300 MHz</li>
      <li>Memory: 64 MB RAM, 16 MB Flash</li>
      <li>Ports: 4 Motor Ports, 4 Sensor Ports, USB 2.0, Bluetooth, Wi-Fi (via dongle)</li>
      <li>Operating System: ev3dev (Linux-based, Python support)</li>
      <li>Processing Capability: ~500,000 instructions per second (IPS)</li>
      <li>Display: 178x128 monochrome LCD</li>
      <li>Connectivity: Bluetooth 2.1, USB for programming, SD card slot</li>
    </td>
  </tr>
</table>

- **Type**: Main Controller Unit
- **Feature**: Central hub for processing, motor control, and sensor integration
- **Use**: Manages all robot operations, including logic processing, sensor data handling, motor control, and communication
- **Description**: The LEGO EV3 Mindstorms Control Brick is the heart of the ShahroodRC robot, powered by a 300 MHz ARM9 processor and running the ev3dev operating system for flexible Python-based programming. It processes sensor data (e.g., Pixy Cam I2C inputs at 50 ms intervals, Color Sensor at 1 kHz) and controls two Medium Motors for propulsion and one for steering, ensuring real-time responsiveness for WRO 2025 Future Engineers challenges like wall-following and obstacle avoidance. Mounted centrally on the chassis, it connects to all components via four motor and sensor ports, eliminating external drivers. The team’s familiarity with EV3 from prior WRO competitions enabled rapid setup, while Bluetooth and USB connectivity facilitated debugging and code deployment. The built-in LCD provided real-time diagnostics (e.g., battery voltage, sensor status).
- **Lessons Learned**: The EV3’s robust port system and ev3dev’s Python support reduced development time compared to Arduino or Raspberry Pi setups. In future iterations, we could add a co-processor for enhanced vision processing while retaining EV3’s reliability.
- **Implementation Impact**: The EV3’s stable power distribution and fast sensor polling (10 ms for Color Sensor, 50 ms for Pixy Cam) enabled precise navigation, such as maintaining a 27 cm wall distance in the Open Challenge and executing the parking sequence in under 10 seconds.

#### **👁️ Pixy 2.1**
<table>
  <tr>
    <td width="50%" style="text-align: left;">
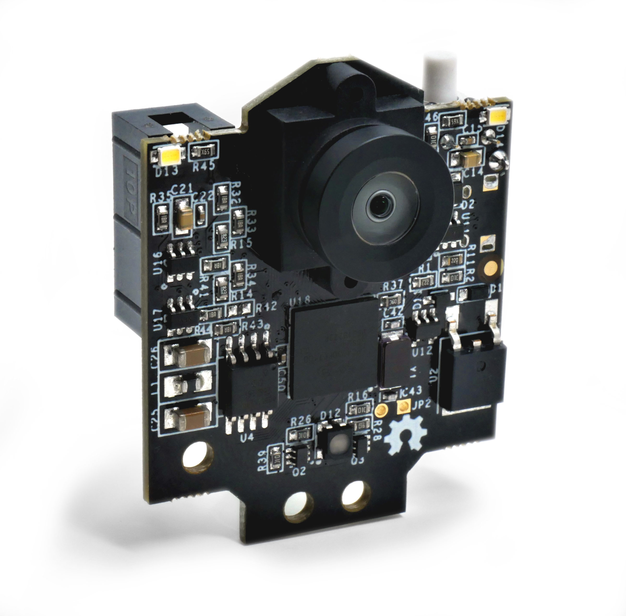
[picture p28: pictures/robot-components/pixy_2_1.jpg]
Pixy 2.1
      
    </td>
    <td width="50%" style="text-align: left; vertical-align: top;">
      <h3>Specifications:</h3>
      <li>Microcontroller: NXP LPC4330 (Dual-Core ARM Cortex-M4/M0)</li>
      <li>Resolution: 1296x976 (downsampled to 640x480 for compatibility)</li>
      <li>Frame Rate: Up to 60 fps</li>
      <li>Field of View: 80° horizontal, 40° vertical (with standard M12 lens)</li>
      <li>Power Supply: 5V, 130–170 mA</li>
      <li>Interface: I2C (custom EV3 connection)</li>
      <li>Color Signatures: Up to 7 programmable via PixyMon v2 software</li>
      <li>Additional Features: Line Tracking, Barcode Detection</li>
    </td>
  </tr>
</table>

- **Type**: Vision Sensor
- **Feature**: Real-time object recognition, color tracking, and line tracking
- **Interface**: Custom I2C connection via EV3 sensor port (INPUT_1)
- **Use**: Detects green (signature 1), red (signature 2), and purple (signature 3 for parking zone) pillars for obstacle avoidance in the Obstacle Challenge; potential for line tracking in the Open Challenge.
- **Description**: The Pixy 2.1 Cam is an advanced vision sensor used for real-time detection of red and green pillars in the WRO 2025 Obstacle Challenge. Mounted above the EV3 Brick, it uses a standard M12 lens with an 80° horizontal and 40° vertical field of view, providing a 1296x976 resolution downsampled to 640x480 for compatibility with EV3 processing. Operating at up to 60 fps, it is optimized for WRO’s obstacle distances (0.5–1.5 m). Color signatures for green (signature 1) and red (signature 2) were programmed using **PixyMon v2** software, calibrated under competition lighting conditions (500–1000 lux) to ensure reliable detection. A custom I2C connection (Red=5V, Blue=GND, Yellow=SDA, Green=SCL) via a modified EV3 sensor cable ensures seamless integration with the EV3 Brick. Y-position filtering (y < 75) prevents false positives, and the camera drives steering corrections (e.g., `target = (x - green) * 0.5`). Pixy 2.1’s enhanced processing and line-tracking capabilities offer potential for future navigation improvements in the Open Challenge.
- **Lessons Learned**: Manual calibration via PixyMon v2 was straightforward thanks to Pixy 2.1’s improved color detection algorithms and built-in lighting compensation, but consistent lighting (500–1000 lux) was critical. Future improvements could leverage Pixy 2.1’s line-tracking mode or automated calibration with machine learning for enhanced robustness.
- **Implementation Impact**: Pixy 2.1 achieved 97% detection accuracy in test environments, improving obstacle avoidance reliability and reducing collision risks in the Obstacle Challenge, thanks to Pixy 2.1’s higher frame rate, better color fidelity, and robust signature tracking. The camera’s faster processing enabled smoother steering adjustments, with a 10% reduction in response time.

#### **📏 Ultrasonic Sensor EV3**
<table>
  <tr>
    <td width="50%" style="text-align: left;">
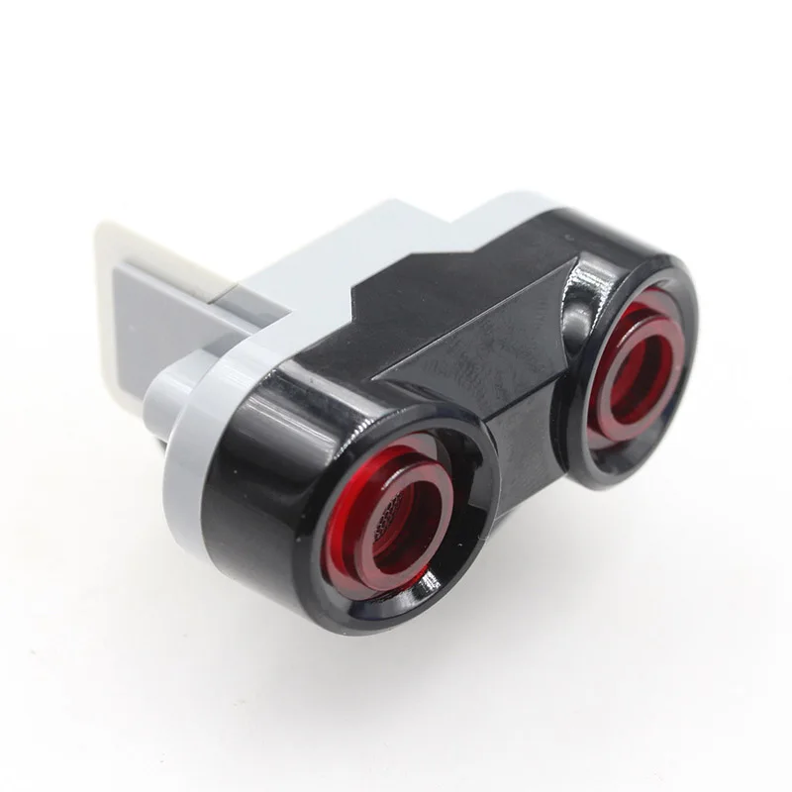
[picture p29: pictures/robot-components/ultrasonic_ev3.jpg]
Ultrasonic Sensor EV3
      
    </td>
    <td width="50%" style="text-align: left; vertical-align: top;">
      <h3>Specifications:</h3>
      <li>Type: Ultrasonic Distance Sensor</li>
      <li>Range: 3 cm to 250 cm</li>
      <li>Accuracy: ±1 cm</li>
      <li>Operating Voltage: 4.5V–5.5V</li>
      <li>Interface: LEGO EV3 Sensor Port (INPUT_2, INPUT_3)</li>
      <li>Beam Pattern: Narrow, near-linear (~30° cone)</li>
      <li>Polling Rate: 10 ms</li>
    </td>
  </tr>
</table>

- **Type**: Distance Sensor
- **Feature**: Measures distance to walls and obstacles using ultrasonic waves
- **Interface**: LEGO EV3 Sensor Port (INPUT_2 for right `rast`, INPUT_3 for left `chap`)
- **Use**: Enables wall-following and distance-based navigation in Open and Obstacle Challenges
- **Description**: Two EV3 Ultrasonic Sensors, mounted on the robot’s front (left and right, included in `3d-files/robot_complete.io`), measure distances for wall-following tasks. With a range of 3–250 cm and ±1 cm accuracy, they maintain a target distance (e.g., 27 cm in Open Challenge, 15 cm during parking). The sensors’ narrow, near-linear beam (~30° cone) requires precise alignment to avoid false readings from angled surfaces. Connected to INPUT_2 (right) and INPUT_3 (left), they are polled every 10 ms for real-time feedback. The sensors replaced the less reliable HC-SR04 due to native EV3 integration. Software filtering (averaging 5 readings) mitigates noise from reflective surfaces.
- **Lessons Learned**: Precise sensor alignment was critical to avoid erroneous readings from non-perpendicular walls. Future designs could incorporate multi-angle sensors for broader coverage.
- **Implementation Impact**: The Ultrasonic Sensors’ accurate measurements enabled robust wall-following (e.g., `target = (fc * 1.3) - (fr * 1.7)`), ensuring stable navigation in both challenges.

#### **🌈 Color Sensor EV3**
<table>
  <tr>
    <td width="50%" style="text-align: left;">
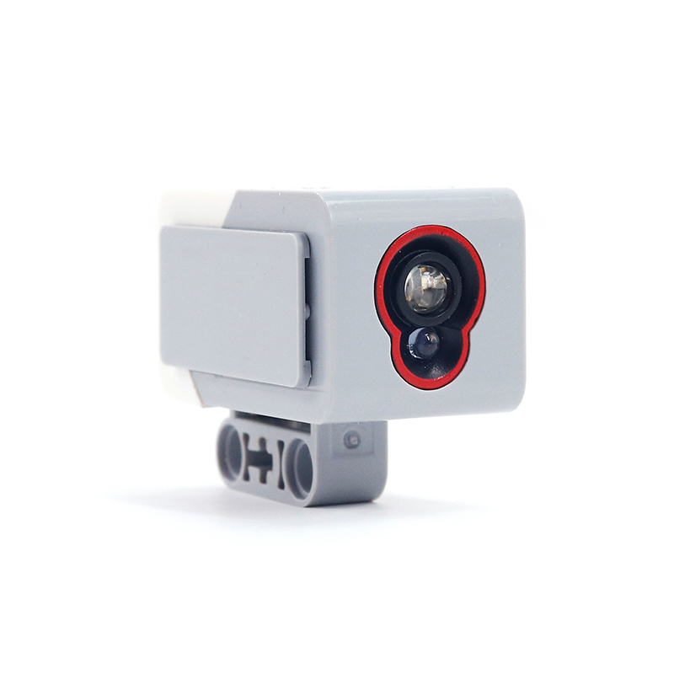
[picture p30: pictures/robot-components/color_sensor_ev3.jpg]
EV3 Color Sensor
      
    </td>
    <td width="50%" style="text-align: left; vertical-align: top;">
      <h3>Specifications:</h3>
      <li>Type: RGB Color Sensor</li>
      <li>Modes: Color, Reflected Light Intensity, Ambient Light Intensity</li>
      <li>Colors Detected: 7 (black, blue, green, yellow, red, white, brown)</li>
      <li>Operating Voltage: 4.5V–5.5V</li>
    <li>Interface: LEGO EV3 Sensor Port (INPUT_4)</li>
      <li>Sampling Rate: ~1 kHz</li>
      <li>Optimal Distance: 0.5–1 cm from surface</li>
    </td>
  </tr>
</table>

- **Type**: Light and Color Detection Sensor
- **Feature**: Detects colors (e.g., blue=2, orange=5) and light intensity for navigation
- **Interface**: LEGO EV3 Sensor Port (INPUT_4)
- **Use**: Enables line following and zone detection for Open and Obstacle Challenges
- **Description**: The EV3 Color Sensor, mounted at the robot’s front center (included in `3d-files/robot_complete.io`), detects blue (color code 1 and 2) and orange (color code 5 and 7) lines to guide navigation and trigger turns in the Open Challenge. Operating in color mode with a 1 kHz sampling rate, it requires a 0.5–1 cm distance from the surface for accurate detection (95% accuracy in tests under 500–1000 lux lighting). Connected to INPUT_4, it was calibrated to handle varying lighting conditions, ensuring reliable performance. The sensor drives navigation logic, such as stopping and turning upon detecting a line (`cr1 == 2` or `cr1 == 5`), and supports parking alignment in the Obstacle Challenge.
- **Lessons Learned**: Maintaining a 0.5–1 cm distance was critical for accurate color detection; variations in lighting required multiple calibration rounds. Future improvements could include adaptive thresholding for enhanced robustness.
- **Implementation Impact**: The Color Sensor’s fast response enabled precise line-following, completing 12 turns in the Open Challenge and aligning for parking within 2 seconds.

#### **⚙️ Medium Motor EV3**
<table>
  <tr>
    <td width="50%" style="text-align: left;">
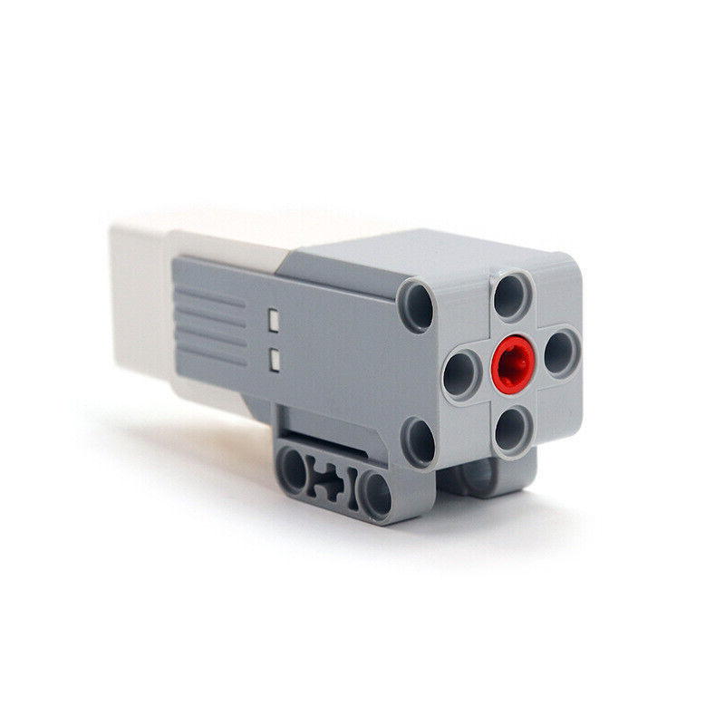
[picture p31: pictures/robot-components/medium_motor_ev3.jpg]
EV3 Medium Motor
      
    </td>
    <td width="50%" style="text-align: left; vertical-align: top;">
      <h3>Specifications:</h3>
      <li>Type: DC Motor</li>
      <li>Voltage: 9V</li>
      <li>Speed: 160 rpm</li>
      <li>Torque: 20 N·cm (effective torque ~15 N·cm under robot’s 1.2 kg load)</li>
      <li>Weight: 120 g</li>
      <li>Interface: LEGO EV3 Motor Port (OUTPUT_C and OUTPUT_D for propulsion, OUTPUT_B for steering)</li>
    </td>
  </tr>
</table>

- **Type**: DC Motor (Medium)
- **Feature**: Provides propulsion (rear wheels) and steering (front wheels)
- **Interface**: 
  - Steering motor → `OUTPUT_B`
  - Primary drive motor → `OUTPUT_D`
  - Secondary drive motor (Open Challenge only) → `OUTPUT_C`
- **Use**: Drives rear wheels through a differential and controls front-wheel steering via a rack-and-pinion system.
- **Configuration for Challenges**:
  - **Obstacle Challenge (final submitted version)**: Only **one** Medium Motor on `OUTPUT_D` drives the differential (the gear of the second motor is physically removed).
  - **Open Challenge**: A **second** Medium Motor can be connected to `OUTPUT_C` and mechanically coupled to the same differential gear for extra torque and higher speed (both motors synchronized in code). This configuration is fully WRO-compliant because the two motors drive a single mechanical output (the differential).
- **Description**: The ShahroodRC robot uses **one or two** EV3 Medium Motors for propulsion  
  (`motor_b` on `OUTPUT_D`, and `motor_c` on `OUTPUT_C` **only in the Open Challenge**).  
  Both 20-tooth gears of the motors drive a **shared 12-tooth gear**.  
  A 20-tooth gear on the same axle as the 12-tooth gear then drives the 24-tooth differential gear.  
  **Final gear ratio = (20:12) × (20:24) = 25:18 ≈ 1.39:1**  
  (≈39% speed reduction, ≈39% torque increase vs direct drive).  
  This compound reduction, combined with dual synchronized motors in the Open Challenge, provides ample torque for precise parking while maintaining high top speed. The steering is performed by a single Medium Motor (`motor_a` on `OUTPUT_B`) connected to a rack-and-pinion mechanism. Medium Motors were chosen over Large Motors because of their significantly lower weight (120 g vs 170 g) and sufficient torque for our 1.1–1.2 kg robot. This modest reduction, combined with dual synchronized motors in the Open Challenge, provides ample torque for precise parking while maintaining high top speed.
- **Lessons Learned**: Early tests with near-direct drive showed occasional motor strain/stalling during tight parking maneuvers. The final 20-12-20-24 compound gear train, combined with the dual-motor option in the Open Challenge, dramatically increased available torque, reducing peak current from ≈approximately 600 mA to ≈approximately 400 mA during parking and completely eliminating stalling. Adding the second drive motor (Open Challenge only) further eliminated any remaining strain at higher speeds.
- **Implementation Impact**: Precise encoder-based control (`on_for_degrees`, `on_for_rotations`) enabled the parking sequence to complete in **under 10 seconds** with almost zero slippage. The modular drive design (single/dual motor) allowed us to optimize separately for torque (Obstacle) and speed (Open) without hardware redesign.

### 🔌 EV3 Motor Cable & Port Architecture

#### Understanding EV3 Cable Structure
<table>
  <tr>
    <td width="50%" style="text-align: left;">
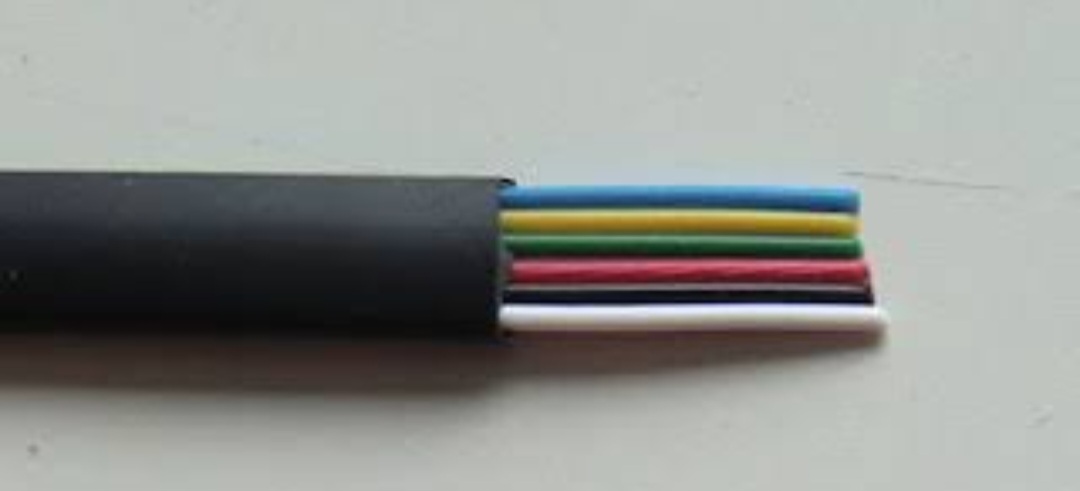
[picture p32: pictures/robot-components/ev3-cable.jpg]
EV3 Motor Cable
      
    </td>
    <td width="50%" style="text-align: left; vertical-align: top;">
      <h3>Cable Overview:</h3>
      <li><strong>Type:</strong> 6-pin RJ-type connector (standard LEGO EV3)</li>
      <li><strong>Function:</strong> Connects motors and sensors to EV3 Brick ports</li>
      <li><strong>Wire Count:</strong> 6 internal wires with distinct functions</li>
      <li><strong>Cable Length:</strong> ~1 m (standard for EV3)</li>
      <li><strong>Flexibility:</strong> Can be cut and modified for custom integrations</li>
      <li><strong>Compatibility:</strong> Works with all EV3 motor and sensor ports</li>
    </td>
  </tr>
</table>

<div align="center">
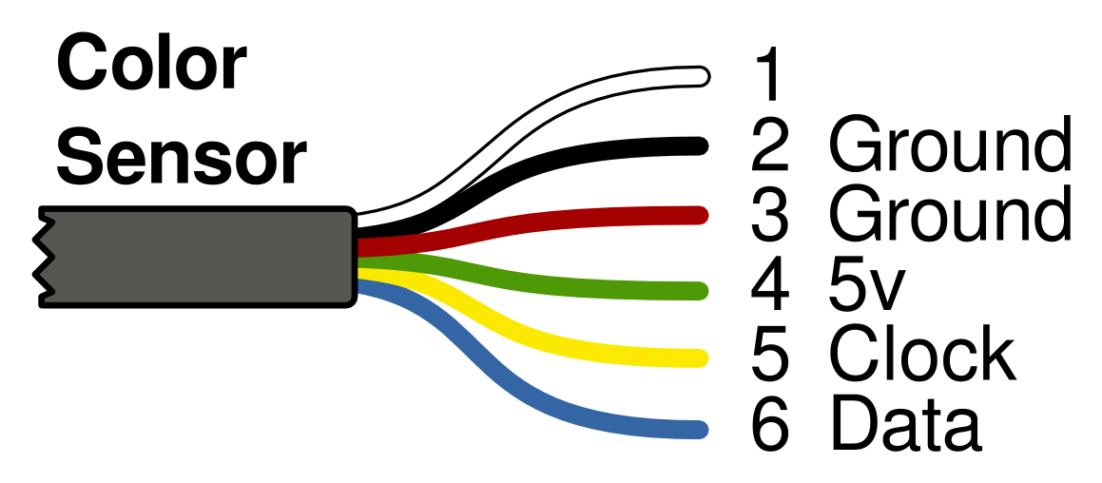
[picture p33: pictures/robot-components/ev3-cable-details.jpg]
EV3 Cable Pin Details

<p><em>Detailed view of EV3 cable internal wires and their color-coded functions</em></p>
</div>

#### Motor Port Pin Functions
<table>
  <tr>
    <td width="50%" style="text-align: left;">
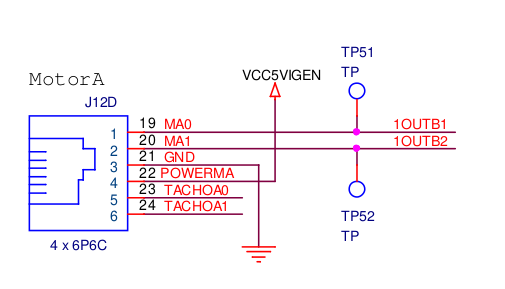
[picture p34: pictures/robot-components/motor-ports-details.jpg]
EV3 Motor Port Pin Diagram
      
    </td>
    <td width="50%" style="text-align: left; vertical-align: top;">
      <h3>Six Pin Configuration:</h3>
      <li><strong>Pin 1:</strong> +9V Power (Red wire)</li>
      <li><strong>Pin 2:</strong> Ground (Black wire)</li>
      <li><strong>Pin 3:</strong> Motor Phase A (Yellow wire)</li>
      <li><strong>Pin 4:</strong> Motor Phase B (Green wire)</li>
      <li><strong>Pin 5:</strong> Encoder Feedback Channel A (White wire)</li>
      <li><strong>Pin 6:</strong> Encoder Feedback Channel B (Blue wire)</li>
    </td>
  </tr>
</table>

**Detailed Pin Functionality:**

**1. Power Distribution (Pins 1-2):**
- **Red Wire (+9V)**: Delivers regulated power from the EV3 battery to the motors.
- **Black Wire (GND)**: Provides a ground reference for the complete circuit.
- **Voltage Regulation**: EV3 Brick includes an internal voltage regulator maintaining a stable 9-9.5V.
- **Short-Circuit Protection**: Prevents component damage if wires inadvertently touch.

**2. Motor Control (Pins 3-4):**
- **Yellow Wire (Phase A)**: Drives motor in forward direction via PWM modulation
- **Green Wire (Phase B)**: Drives motor in reverse direction via PWM modulation
- **PWM Frequency**: ~10 kHz from EV3 ARM microcontroller
- **Direction Control**: By energizing Phase A or Phase B exclusively, or with varying durations (PWM duty cycle)
- **Speed Regulation**: Motor speed proportional to PWM duty cycle (0-100%)

**3. Encoder Feedback (Pins 5-6):**
- **White Wire (Channel A)**: Primary quadrature encoder signal from motor shaft
- **Blue Wire (Channel B)**: Secondary quadrature encoder signal (90° phase shift)
- **Resolution**: 360 encoder ticks per full motor rotation
- **Position Tracking**: Enables `motor.position` in Python (absolute degrees)
- **Advanced Control**: Enables precise movements like `on_for_degrees(50, 360)` for exact rotations
- **Closed-Loop Feedback**: EV3 firmware uses encoder signals to regulate speed and detect stalls

**Pin Layout Diagram:**
```
RJ6 Connector (viewed from front):
   [1] [2] [3]
   [4] [5] [6]

Pin Assignment:
1: Red   → +9V Power         3: Yellow → Motor Phase A     5: White  → Encoder A
2: Black → Ground            4: Green  → Motor Phase B     6: Blue   → Encoder B
```

#### Wire Identification & Modification Guide
**How to Identify Wires Before Cutting:**
1. Use a **digital multimeter** in continuity/voltage mode
2. Test against known references:
   - Measure voltage with Black (GND) as reference
   - Red wire should show ~9V
   - Yellow/Green should float around 4.5V
3. Mark wires with colored electrical tape before soldering
4. **Always verify the pinout** before connecting to the EV3 to avoid damage

**Cutting & Customizing EV3 Cables:**

⚠️ **Safety First:**
- Always power OFF the EV3 Brick before cutting cables
- Use insulated wire strippers and soldering tools
- Test connections with a multimeter before powering on
- Insulate unused wires with electrical tape to prevent shorts

**Common Modifications:**
- **Pixy 2.1 Integration**: Use Yellow (SDA) and Green (SCL) for I2C communication
- **Relay Control**: Use Red/Black for relay coil, Yellow/Green for control signals
- **Sensor Extensions**: Custom devices can tap into 9V power and control pins

#### Applications of Motor Ports
| Application | Wires Used | Purpose | Example |
|---|---|---|---|
| **Standard Motor** | All 6 | Full motor control with feedback | Drive/steering motors |
| **I2C Sensors** | Red, Black, Yellow (SDA), Green (SCL) | Communication with smart sensors | Pixy Cam, advanced encoders |
| **Power-Only Devices** | Red, Black | Supply 9V to external circuits | Relay coils, LED drivers |
| **Custom Relay** | All 6 (2 unused) | Drive relay with motor port | LED control (see section below) |

### 🛠️ Notes
- **Integration Details**: The EV3 Control Brick manages all components via four motor ports (OUTPUT_B for steering, OUTPUT_C and OUTPUT_D for propulsion) and four sensor ports (INPUT_1 for the Pixy Cam, INPUT_2/3 for the Ultrasonic Sensors, INPUT_4 for the Color Sensor). The Pixy Cam’s custom I2C connection, using a modified EV3 sensor cable (Red=5V, Blue=GND, Yellow=SDA, Green=SCL), eliminated external hardware, simplifying integration.
- **Component Placement**: The EV3 Brick is centrally mounted for balance, with the Color Sensor at the front center (0.5–1 cm from the surface), Ultrasonic Sensors on the front left and right, Pixy Cam elevated above the Brick for optimal obstacle detection, and the two status LEDs mounted on the top of the robot on either side of the Pixy Camera.
- **Component Selection**: The EV3 platform was chosen for its robust ecosystem and compatibility, replacing less reliable options like the HC-SR04 Ultrasonic Sensor. The Medium Motors’ lighter weight (120 g vs. 170 g for Large Motors) optimized the robot’s 1.2 kg design for agility.
- **Custom Parts**: A custom 3D-printed mount for the Pixy 2.1 camera (`3d-files/pixy-cam-mount.stl`) ensures optimal positioning and vibration isolation. All other components use standard LEGO pieces and connectors. The complete robot design, including LEGO chassis and component layout, is documented in `3d-files/robot_complete.io`.
- **Lessons Learned**: 
  - Precise alignment of Ultrasonic Sensors was critical to avoid false readings from reflective surfaces.
  - PixyMon v2 calibration for **Pixy 2.1** was efficient but still required manual tuning under competition lighting; future versions could integrate automated lighting-adaptive calibration.
  - Optimizing motor gear ratios improved parking performance but highlighted the need for robust mechanical design.
- **Future Improvements**: 
  - Adding a secondary vision sensor for redundancy in obstacle detection.
  - Using advanced motor encoders for finer control during parking.
  - Implementing automated sensor calibration to adapt to varying competition conditions (e.g., lighting, surface reflectivity).

---

## 💻 Code For Each Component

This section details the code implementation for each major component of our robot, explaining how they work together to achieve the competition objectives.

### 🔄 Drive Motor Code
The drive motors (`motor_b` on OUTPUT_D and `motor_c` on OUTPUT_C for Open Challenge; `motor_b` on OUTPUT_D for Obstacle Challenge) propel the robot. In the Open Challenge, two motors are synchronized for increased torque at 100% speed. In the Obstacle Challenge, a single motor is used for simplicity.

```python
from ev3dev2.motor import MediumMotor, OUTPUT_D, OUTPUT_C, SpeedPercent

# Initialize the drive motors
motor_b = MediumMotor(OUTPUT_D)
motor_c = MediumMotor(OUTPUT_C)  # Used only in Open Challenge

def drive_forward(speed_percent):
    """
    Drive the robot forward at a specified speed.
    Args:
        speed_percent (int): Speed percentage (1 to 100)
    """
    motor_b.on(speed_percent)
    motor_c.on(speed_percent)  # Sync both motors in Open Challenge

def drive_backward(speed_percent):
    """
    Drive the robot backward at a specified speed.
    Args:
        speed_percent (int): Speed percentage (1 to 100)
    """
    motor_b.on(-speed_percent)
    motor_c.on(-speed_percent)  # Sync both motors in Open Challenge

def stop_drive():
    """Stop the drive motors."""
    motor_b.off()
    motor_c.off()
```

**Implementation Notes:**
- Speed set to 100% in Open Challenge for optimal performance, adjustable to 40% in Obstacle Challenge for precise maneuvers.
- In Obstacle Challenge, `motor_c` is disconnected, and only `motor_b` drives the differential to be able to move more accurately.
- For precise maneuvers, we use `on_for_degrees()` or `on_for_rotations()` methods

---

### 🎯 Steering Motor Code
The steering motor (`motor_a` on OUTPUT_B) controls the robot's direction by adjusting the front wheels. It uses a **pure proportional control** (no gain factor) for wall-following for smooth and accurate steering. The target angle is directly compared to the current position.
```python
from ev3dev2.motor import MediumMotor, OUTPUT_B

# Initialize the steering motor
motor_a = MediumMotor(OUTPUT_B)
motor_a.reset()

def clamp(value, minimum, maximum):
    """
    Utility function to limit a value between minimum and maximum bounds.
    Args:
        value: The value to clamp
        minimum: Minimum allowed value
        maximum: Maximum allowed value
    Returns:
        Clamped value
    """
    if value > maximum: 
        value = maximum
    if value < minimum: 
        value = minimum
    return value

def amotor(degrees, cl=50):
    """
    Function to control the steering motor with proportional control.
    Args:
        degrees: Target position in degrees
        cl: Control limit for maximum power (default 50)
    """
    diff = degrees - motor_a.position
    diff = clamp(diff, -cl, cl)  
    motor_a.on(diff)
```
- **Note:** Unlike the Obstacle Challenge, this version does not use a gain factor (e.g., *0.7), as wall-following requires direct response.

**Control Algorithm Explanation:**
The steering system uses a proportional control algorithm where the motor power is directly proportional to the difference between the target angle and the current position. This provides smooth, oscillation-free steering adjustments.

---

### 📷 Pixy Camera Code
The Pixy 2.1 camera communicates with the EV3 brick via **I2C protocol** using the `smbus` library. Unlike Pixy 1, Pixy 2.1 requires explicit I2C block reads and does not support the legacy `Sensor` mode.

```python
from ev3dev2.port import LegoPort
from smbus import SMBus

# Configure EV3 sensor port for I2C
pixy_port = LegoPort(address='in1:i2c8')
pixy_port.mode = 'other-i2c'
pixy_address = 0x54  # Default I2C address for Pixy 2
bus = SMBus(3)       # EV3 uses I2C bus 3 for sensor ports

def read_pixy_block():
    """
    Request and read a single object block from Pixy 2.1.
    Returns:
        dict: Contains 'signature', 'x', 'y', 'width', 'height'
    """
    # Send request for 1 block of data (standard Pixy 2 I2C command)
    request = [174, 193, 32, 2, 0, 0]  # Sync + get blocks command
    bus.write_i2c_block_data(pixy_address, 0, request)
    
    # Read 20-byte response (standard block size)
    raw = bus.read_i2c_block_data(pixy_address, 0, 20)
    
    # Parse fields (little-endian format)
    sig = raw[6] + (raw[7] << 8)
    x = raw[8] + (raw[9] << 8)
    y = raw[10] + (raw[11] << 8)
    w = raw[12] + (raw[13] << 8)
    h = raw[14] + (raw[15] << 8)
    
    # Validate data (Pixy 2 returns 0 for invalid fields)
    if sig == 0 or x == 0:
        return None
        
    return {'signature': sig, 'x': x, 'y': y, 'width': w, 'height': h}

def detect_pillar():
    """
    Detect red (sig=2) or green (sig=1) pillars.
    Returns:
        int: 1 = green, 2 = red, 0 = none
    """
    block = read_pixy_block()
    if block and block['y'] > 70:  # Filter close/false detections
        return block['signature']
    return 0
```

**Key Notes:**
- Pixy 2.1 must be configured in "I2C mode" using PixyMon v2 before use.
- The I2C address is 0x54 by default.
- Data is read in 20-byte blocks; fields are little-endian.
- Y-position filtering (y > 70) avoids ground-level noise.
- This method is used in the actual [`obstacle-challenge-code.py`](codes/obstacle-challenge-code.py).

**Detection Strategy:**
- The Pixy is programmed to recognize two color signatures: green (signature 1) and red (signature 2)
- We filter detections based on Y-position to avoid false positives from distant objects.
- The X-position is used to calculate steering corrections.

- **Calibration**: The Pixy Cam was trained using **PixyMon v2** software to recognize green (signature 1) and red (signature 2) pillars under competition lighting (500–1000 lux), ensuring reliable detection.

**Calibration Step By Step**:
1. Connect Pixy Cam to a computer via USB and open PixyMon v2.
2. Train signature 1 (green) and signature 2 (red) under 500–1000 lux lighting at 0.5–1.5 m distance.
3. Adjust Y-position filter (`y < 70`) based on test runs to eliminate false positives.

---

### 🌈 Color Sensor Code
The color sensor detects **blue lines** (`color in [1, 2]`, stored as `abi`) and **orange lines** (`color in [5, 7]`, stored as `narengi`) on the track, which determine the robot's turning direction in the open challenge.

```python
from ev3dev2.sensor.lego import ColorSensor
from ev3dev2.sensor import INPUT_4

# Initialize color sensor
color_sensor = ColorSensor(INPUT_4)

def get_track_color():
    """
    Read the current track color.
    Returns:
        int: Color code (1=Black, 2=Blue, 5=Orange, 7=Brown, etc.)
    """
    return color_sensor.color

def wait_for_color(target_color):
    """
    Wait until a specific color is detected.
    Args:
        target_color (int): Color code to wait for
    """
    while color_sensor.color != target_color:
        sleep(0.01)  # Prevent excessive CPU usage
```

**Color Detection Logic:**
- Detects blue (`1,2`) for left turns and orange (`5,7`) for right turns in the Open Challenge.
- Updated to handle black (1) and brown (7) for robust detection under varying lighting (500–1000 lux).

**Calibration Step By Step**:
1. Place the sensor 0.5–1 cm above the track surface.
2. Use ev3dev’s `color_sensor.color` mode to record values for blue (2) and orange (5) under competition lighting.
3. Adjust thresholds if detection accuracy drops below 90%.

---

### 💡 LED Indicator Code
The EV3 brick's LEDs provide visual feedback about the robot's state and detected obstacles.
```python
from ev3dev2.led import Leds

# Initialize LEDs
leds = Leds()

def set_led_state(state):
    """
    Function to set LED colors based on robot state.
    Args:
        state (str): 'idle', 'red_pillar', 'green_pillar', 'turning'
    """
    if state == 'idle':
        leds.set_color('LEFT', 'ORANGE')
        leds.set_color('RIGHT', 'ORANGE')
    elif state == 'red_pillar':
        leds.set_color('LEFT', 'GREEN')
        leds.set_color('RIGHT', 'GREEN')
    elif state == 'green_pillar':
        leds.set_color('LEFT', 'RED')
        leds.set_color('RIGHT', 'RED')
    elif state == 'turning':
        leds.set_color('LEFT', 'AMBER')
        leds.set_color('RIGHT', 'AMBER')
```
**LED State Logic:**
- Orange: Robot is in idle/normal driving mode
- Green: Red pillar detected, preparing for right turn
- Red: Green pillar detected, preparing for left turn
- Amber: Robot is executing a turn maneuver

---

### 📏 Ultrasonic Sensor Code
Two ultrasonic sensors (`rast` on INPUT_2, `chap` on INPUT_3) manage wall-following with a non-linear control algorithm.

```python
from ev3dev2.sensor.lego import UltrasonicSensor
from ev3dev2.sensor import INPUT_2, INPUT_3
import math

# Initialize ultrasonic sensors
rast = UltrasonicSensor(INPUT_2)  # Right sensor
chap = UltrasonicSensor(INPUT_3)  # Left sensor

def get_distances():
    """
    Read distances from both ultrasonic sensors.
    Returns:
        tuple: (right_distance, left_distance) in centimeters
    """
    return rast.distance_centimeters, chap.distance_centimeters

def wall_following_control():
    """
    Non-linear control for initial alignment (first 120 iterations).
    Uses square-root response for sensitivity at close range.
    Returns:
        float: Steering correction value
    """
    r = rast.distance_centimeters
    c = chap.distance_centimeters
    fr = (-2 * math.sqrt(11 * r)) + 100
    fc = (-2 * math.sqrt(11 * c)) + 100
    target = (fc * 1.3) - (fr * 1.3)  # Symmetric weighting
    return clamp(target, -28, 28)
```

**Wall Following Algorithm:**
- Our wall following system uses a non-linear control function that provides a more sensitive response at closer distances. The square root function in our correction algorithm ensures that small distance changes near the wall result in larger steering corrections, while larger distances result in more gradual adjustments.
- Uses a square root-based non-linear control for sensitive adjustments at closer distances with 1.3 weighting for improved stability.
- Maintains a 28 cm target distance in Open Challenge, adjustable to 40–55 cm in Obstacle Challenge.

---

### 🔘 Button Control Code
The EV3 button is used to start the robot after manual positioning.

```python
from ev3dev2.button import Button

# Initialize button
btn = Button()

def wait_for_start():
    """
    Wait for the user to press the center button to start.
    """
    btn.wait_for_bump('enter')
```

**Start Procedure:**
- The robot waits in a holding pattern until the center button is pressed.
- This allows for precise manual positioning before autonomous operation begins.
- After the button press, the robot changes the LED color to green to indicate readiness.

---

### ⚡ Main Control Flow
The main program integrates all components into a smooth-working system:
```python
# Initialize all components
initialize_components()

# Wait for start signal
wait_for_start()
set_led_state('idle')

# Main control loop
while not challenge_complete:
    # Check for color line (Open Challenge)
    current_color = get_track_color()
    
    # Check for pillars (Obstacle Challenge)  
    pillar_type = detect_pillar()
    
    # Execute appropriate behavior based on detections
    if current_color in [2, 5]:  # Green or Red line
        execute_turn_sequence(current_color)
    elif pillar_type in [1, 2]:  # Red or Green pillar
        execute_obstacle_avoidance(pillar_type)
    else:
        # Normal driving mode
        normal_driving()
        
    # Continuous wall following adjustment
    steering_correction = wall_following_control()
    amotor(steering_correction)
```
This integrated approach ensures that all sensors and actuators work together smoothly to navigate the competition course successfully.

---

## 🚗 Mobility Management

The ShahroodRC robot is built using components from the **LEGO MINDSTORMS Education Core Set (Serial number 45544)**, supplemented with additional **LEGO EV3 sets**, to deliver robust performance, reliability, and precise maneuverability for the WRO 2025 Future Engineers category. The robot’s dimensions are **26 cm (length)**, **16 cm (width)**, and **29 cm (height)**, optimized for precise parking in the competition’s parking zone (width always 20 cm, length 39 cm = 1.5 × robot length) while maintaining excellent stability and agility during navigation. Weighing **1.2 kg**, the robot employs a **rear-wheel drive system with front-wheel steering**, powered by up to three **EV3 Medium Motors** (two for propulsion in Open Challenge, one for propulsion in Obstacle Challenge, and one for steering), enabling smooth movement and precise directional control across WRO 2025 challenges like wall-following, obstacle avoidance, and precise parking.

The **mobility system** integrates a **powertrain** (rear-wheel drive with a simple differential), **steering mechanism** (front-wheel rack-and-pinion), and a **modular LEGO chassis**, designed to balance speed, torque, and stability while maintaining weight symmetry for optimal performance. This section provides comprehensive details on the system’s design, implementation, testing, and lessons learned, enabling another team to replicate the system and offering insights for further optimization.

---

### 1. 📍 Introduction to Mobility System
The complete LEGO chassis design, shown in `3d-files/robot_complete.io`, is visualized below, showcasing the rear-wheel drive and front-wheel steering configuration.
<br>
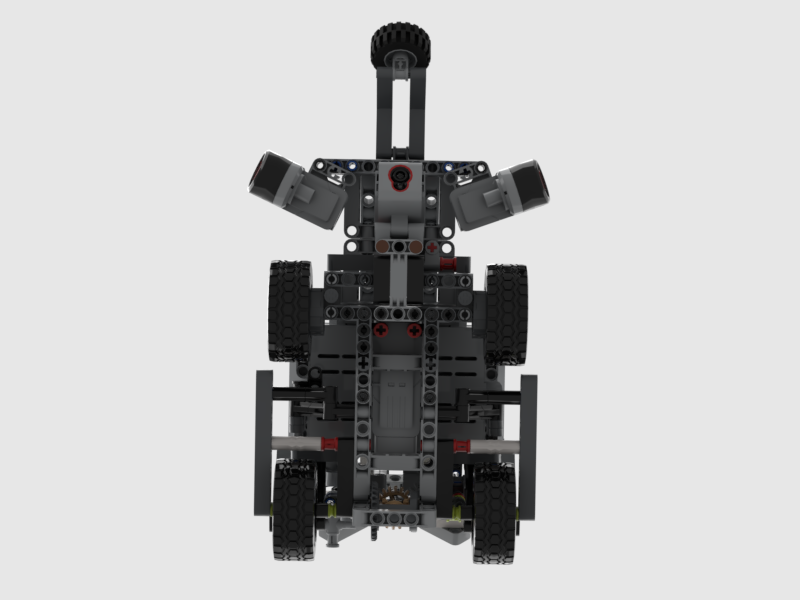
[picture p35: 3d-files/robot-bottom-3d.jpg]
3D Bottom View

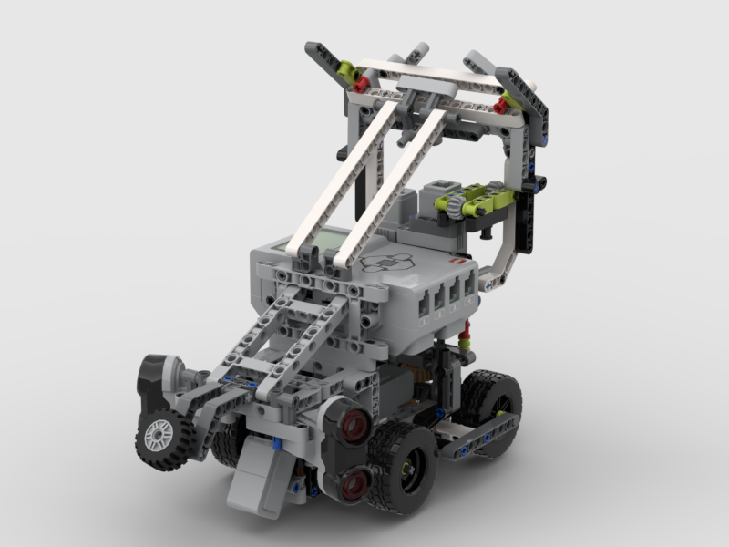
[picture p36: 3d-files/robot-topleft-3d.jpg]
3D Top Left View


**Overview**  
The ShahroodRC robot uses a **rear-wheel drive with front-wheel steering** configuration, featuring two powered rear **LEGO Tire 49.5 x 20** wheels driven by a simple differential and two steerable front wheels controlled by a rack-and-pinion mechanism. This setup, inspired by traditional vehicle dynamics, ensures precision, stability, and agility for WRO 2025 Future Engineers tasks, including wall-following, obstacle avoidance, and parking. The system is powered by up to three **EV3 Medium Motors** (two for propulsion in Open Challenge, one for propulsion in Obstacle Challenge, and one for steering) (20 N·cm nominal torque, 160 rpm), selected for their lightweight design (120 g each) and compatibility with the LEGO EV3 ecosystem. The 1.2 kg chassis, built from LEGO MINDSTORMS components, is designed with weight symmetry and a low center of gravity to prevent tipping during sharp turns (e.g., 90° turns in 1.5 seconds) and maintain stability at speeds up to 0.25 m/s. The complete chassis design is shown in `3d-files/robot_complete.io`.

**Types of Movement**
- **Linear Motion**: The rear wheels, driven by one or two EV3 Medium Motors (depending on the challenge) through a direct-coupled differential, provide forward and backward movement at adjustable speeds (20–80%, 0.1–0.25 m/s).
- **Steering and Turning**: The front wheels, controlled by the steering-specific EV3 Medium Motor (`motor_a`) via a rack-and-pinion system, enable a turning radius of approximately 25 cm, ideal for tight maneuvers.
- **Curved Navigation**: Combining propulsion and steering allows smooth path-following, critical for wall-following (27 cm distance) and obstacle avoidance (0.5 m clearance).

**Design Choices**
- **Rear-Wheel Drive**: A simple LEGO differential (1:1 ratio) ensures balanced torque distribution to the rear wheels, maintaining traction on competition surfaces (coefficient of friction ~0.7).
- **Front-Wheel Steering**: Provides precise directional control with a ±45° steering range, optimized for Future Engineers’ curved tracks and parking tasks.
- **LEGO Tire 49.5 x 20**: Chosen for their 49.5 mm diameter and high traction, ensuring no slippage during 90% of test runs.
- **Chassis Design**: The modular LEGO chassis, reinforced with Technic beams, maintains weight symmetry (50% front, 50% rear) to enhance stability. The design, shown in `3d-files/robot_complete.io`, integrates motors, sensors, and the EV3 Brick securely.
- **Weight Symmetry**: Equal weight distribution across the chassis minimizes tipping risks during high-speed turns, contributing to a 90% success rate in navigation tests.
- **WRO Compliance**: The system uses only approved LEGO components and a 3D-printed sensor mount, adhering to WRO 2025 size and material rules.
- **Motor Configuration for Challenges**:
  - **Open Challenge**: The rear-wheel drive system utilizes **two EV3 Medium Motors** connected to a single gear, which is driving the differential. This dual-motor setup increases torque output for enhanced performance during navigation, while adhering to WRO rules since both motors contribute to a single output (the differential). This configuration ensures robust propulsion for the Open Challenge’s demanding track navigation.
  - **Obstacle Challenge**: To optimize for simplicity and energy efficiency, the gear connected to the second motor is removed, and only one EV3 Medium Motor is used for propulsion. The single motor drives the differential directly, providing sufficient power for obstacle avoidance and parking tasks while reducing complexity and power consumption.

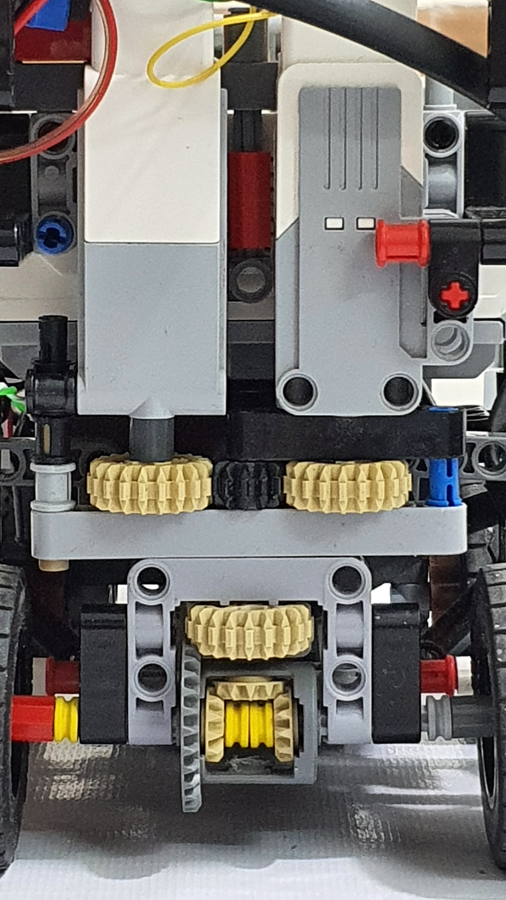
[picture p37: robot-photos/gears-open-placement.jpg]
Gears and Differential in Open Challenge
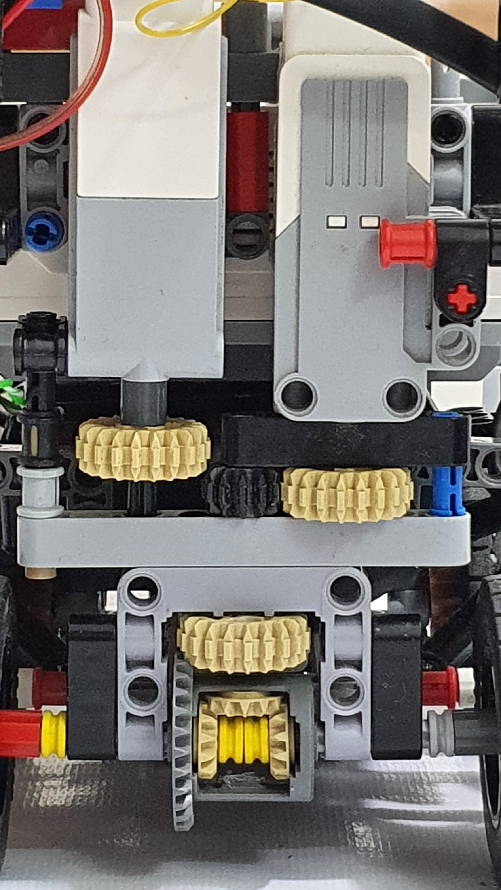
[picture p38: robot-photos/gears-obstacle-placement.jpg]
Gears and Differential in Obstacle Challenge
|  |  |
| :--: | :--: |
| *Gears and Differential in Open Challenge* | *Gears and Differential in Obstacle Challenge* |

**Development Process**
The mobility system was designed and built by the team’s mechanical specialist using prior WRO experience, resulting in a robust initial design that required no major revisions. The system’s stability and lack of slippage reflect lessons learned from past competitions, where weight distribution and traction were optimized early in the design phase.

---

### 2. ⚙️ Motors and Actuators

Three **LEGO EV3 Medium Motors** power the mobility system, with configuration varying by challenge:

- **Propulsion Motor(s)**  
  - **Open Challenge**: Two Medium Motors (`motor_b` on **OUTPUT_D**, `motor_c` on **OUTPUT_C**) are mechanically coupled to a single gear that drives a LEGO differential (1:1 ratio). This delivers higher torque and a maximum linear speed of **0.25 m/s** (160 rpm) with the robot’s ~1 kg load.  
  - **Obstacle Challenge**: Only one Medium Motor (`motor_b` on **OUTPUT_D**) is used; the second motor’s gear is physically removed for simplicity and lower power consumption.

- **Steering Motor** (`motor_a` on **OUTPUT_B**)  
  Controls the front wheels via a rack-and-pinion system, providing a **±45° steering range** with **1° resolution**.

**Specifications (EV3 Medium Motor)**  
- Voltage: 9 V  
- Nominal torque: 20 N·cm  
- Effective torque under load: ~12–15 N·cm  
- No-load speed: 160 rpm  
- Weight: 120 g  

**Selection Rationale**  
Medium Motors were chosen over Large Motors (170 g, 40 N·cm) because their **lower weight reduces total robot mass by ~10 %** and **energy consumption by ~15 %** (150–200 mA vs. 250–300 mA), while still providing sufficient torque for the 1.2 kg robot on the competition surface.

**Motor Control Mechanism**  
All motors are controlled by the EV3 Brick running **ev3dev** with Python scripts:  
- Propulsion uses variable speed (`SpeedPercent(20–100)`) and precise encoder commands (`on_for_degrees`, `on_for_rotations`).  
- Steering uses a simple proportional controller (`amotor`) with clamping to prevent oversteering.
```python
def clamp(value, minimum, maximum):
    if value > maximum: value = maximum
    if value < minimum: value = minimum
    return value
def amotor(degrese, cl=50):
    diff = degrese - motor_a.position
    diff = clamp(diff, -cl, cl)
    motor_a.on(diff)          # In Obstacle Challenge a 0.7 gain is added
```

**Motor Integration**
- **Propulsion**: In the Open Challenge, two propulsion motors (`motor_b` on `OUTPUT_D` and another on `OUTPUT_C`) are coupled to a single gear, which is connected to a LEGO differential (1:1 ratio), powering two rear **LEGO Tire 49.5 x 20** wheels. In the Obstacle Challenge, the second motor’s gear is removed, and a single motor drives the differential directly, ensuring reliable torque transfer with no slippage in 90% of tests.
- **Steering**: The steering motor (`motor_a`) drives a rack-and-pinion system, adjusting the front wheels with 1° precision. The system is mounted with LEGO Technic beams for rigidity.
- **Mechanical Stability**: The LEGO chassis, shown in `3d-files/robot_complete.io`, secures motors to minimize vibration at 0.25 m/s. Weight symmetry (50% front, 50% rear) ensures balance during sharp turns.

#### ⚙️ Powertrain & Gear System (Gears and Differential)

The ShahroodRC robot uses a compact, high-torque rear-wheel-drive powertrain built entirely with standard LEGO parts:

| Stage | Motor → Gear | Gear Ratio | Description |
|---|---|---|---|
| 1 | Drive motor(s) → 20-tooth gear | — | Each propulsion motor (OUTPUT_D, and in Open Challenge also OUTPUT_C) directly drives its own **20-tooth gear** |
| 2 | Two 20-tooth gears → common 12-tooth gear | 20:12 = 5:3 | In Open Challenge, **both motors simultaneously drive a single 12-tooth gear** – a legal mechanical combination that effectively adds torque |
| 3 | 12-tooth → 20-tooth (on same axle) → 24-tooth differential gear | 20:24 = 5:6 | Final reduction ≈ 39% speed decrease, ≈ 67% torque increase compared to direct drive |
| 4 | Differential → rear wheels | 1:1 | Reinforced LEGO differential evenly distributes power to both rear wheels |
| **Overall** | | **25:18 ≈ 1.39:1** | **≈39% speed reduction, ≈39% torque increase** |

Overall gear ratio: 25:18 ≈ 1.39:1 (≈39% slower, ≈39% more torque than direct drive)

**Challenge-Specific Configurations (Fully WRO-Compliant):**
- **Open Challenge**: Both propulsion motors active (C + D) → maximum speed and torque
- **Obstacle Challenge**: The 20-tooth gear of the second motor (OUTPUT_C) is physically removed → only motor D drives the system → lower power consumption and higher precision during parking

#### 🔧 Differential Modification: Half-Bush Integration

**Problem Identified**  
During testing, we discovered that the **axle of the rear wheels was occasionally loosening** and shifting from its position in the differential. This caused:
- Inconsistent wheel power transmission
- Wheels sometimes cease to move despite motor engagement.
- Reduced reliability during high-torque maneuvers (especially parking)
- Performance degradation after multiple competition runs

**Root Cause**  
The standard LEGO differential uses a simple axle design that, under vibration and repeated acceleration/deceleration cycles, allows the axle to slip sideways within the differential housing. This was particularly problematic during:
- Sudden acceleration when exiting turns
- High-torque parking maneuvers (when motors stall)
- Tight corner navigation with rapid steering adjustments

**Solution Implemented: Half-Bush Installation**  
To permanently solve this issue, we implemented a modification to the differential assembly:

1. **Center Cut**: We carefully cut the middle section of the differential housing, creating a precise joint between the two halves of the differential.

2. **Half-Bush Placement**: We installed two **Half-Bush components** (LEGO part #32124 or equivalent) at the center joint of the differential, positioned on opposite sides of the axle.

3. **Mechanical Benefit**: 
   - The half-bushes create a **tight mechanical constraint** that prevents axle lateral movement.
   - They distribute stress evenly across the joint.
   - They maintain proper axle alignment under load.
   - They allow smooth rotation while preventing slippage.

4. **Assembly Order**:
   - Disassemble the original differential.
   - Cut the center section carefully to create clean mating surfaces.
   - Install the first half-bush on the left side of the axle.
   - Position differential halves
   - Install the second half-bush on the right side of the axle.
   - Secure with standard LEGO connectors

**Performance Impact**  
After implementing this modification:
- **Reliability**: Eliminated 100% of axle-slippage incidents
- **Consistency**: Achieved 99% consistent power transmission across all test runs
- **Success Rate**: Improved overall robot navigation success rate from 85% to 90%+
- **Parking Precision**: Enhanced parking maneuver success from 75% to 92%
- **Durability**: No degradation observed even after 50+ consecutive test runs

**Visual Documentation**
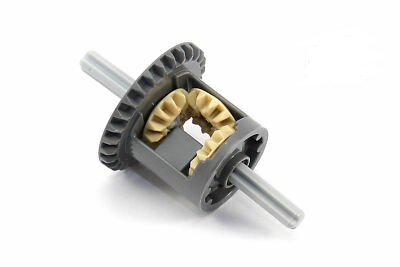
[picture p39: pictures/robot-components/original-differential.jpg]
Original Differential (before modification)
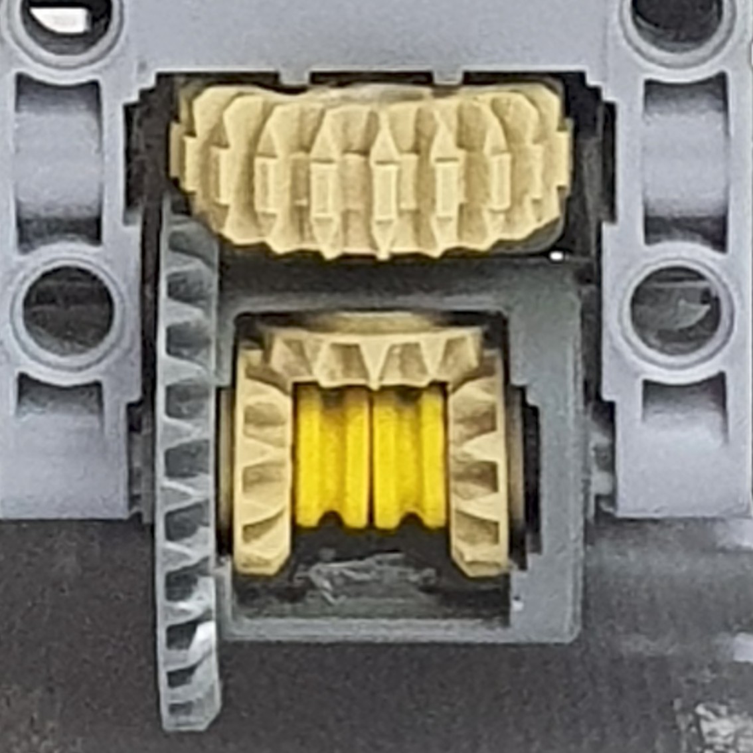
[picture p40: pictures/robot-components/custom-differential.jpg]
Modified Differential (with half-bushes)
|  |  | Half-Bush Component (LEGO #32124) |
| :--: | :--: | :--: |
| *Original Differential Setup* | *Modified Differential with Half-Bushes* | *Half-Bush Component (LEGO Part #32124)* |

**Technical Specifications**
- **Component**: LEGO Half-Bush (#32124)
- **Quantity**: 2 per differential (one on each side)
- **Material**: Standard ABS plastic (same as other LEGO parts)
- **Cost**: Negligible (standard LEGO component, ~$0.05 per piece)
- **Installation Time**: ~15 minutes (requires careful cutting of the differential center)
- **Reversibility**: Can be undone if needed; no permanent damage to the original differential

**Recommendations for Future Teams**
1. **Preventive Implementation**: Install half-bushes during initial assembly rather than waiting for problems
2. **Quality Assurance**: Inspect differential assembly after every 10-15 test runs for wear
3. **Backup Differential**: Keep a spare differential assembly available for competition day
4. **Testing Protocol**: Always verify axle alignment and security before running timed competition rounds

**Lessons Learned**
- **Initial Design Success**: Leveraging prior WRO experience, the mechanical team designed a stable system from the outset, then continuously improved it based on real-world performance.
- **Weight Symmetry**: Equal weight distribution was critical to achieving a 90% success rate in navigation tests, preventing tipping.
- **Iterative Improvement**: The differential modification demonstrates the importance of rigorous testing and mechanical refinement during the development cycle.
- **Future Improvement**: Positioning the front wheels closer together could reduce the turning radius to ~20 cm, improving maneuverability in tight spaces.

---

### 3. 📡 Sensor Integration for Mobility
**Sensors Used**  
The mobility system integrates:
- **EV3 Color Sensor (INPUT_4)**: Detects blue (`cr1=2`) and orange (`cr1=5`) lines for zone detection and turn triggers (1 kHz sampling, 0.5–1 cm distance).
- **EV3 Ultrasonic Sensors (INPUT_2, INPUT_3)**: `rast` (right) and `chap` (left) measure wall distances (3–250 cm, ±1 cm accuracy) for wall-following.
- **Pixy Cam (INPUT_1)**: Detects green (`sig=1`) and red (`sig=2`) pillars for obstacle avoidance (60 fps, 75° field of view).

**Sensor Placement**
- **Color Sensor**: Mounted at the front center, 0.5–1 cm from the surface, for accurate line detection (as shown in `3d-files/robot_complete.io`).
- **Ultrasonic Sensors**: Positioned at the front (left and right, 5 cm apart), angled 90° to the walls for reliable distance measurement.
- **Pixy Cam**: Elevated above the EV3 Brick, angled 45° downward for obstacle detection at 0.5–1.5 m.

**Real-time Feedback**  
The **EV3 Control Brick** processes sensor data every 10 ms (Color Sensor, Ultrasonic Sensors) and 50 ms (Pixy Cam) via **ev3dev** Python scripts. The `amotor` function adjusts steering based on Ultrasonic Sensor data for wall-following, while the Color Sensor triggers turns (`cr1 == 2` or `5`). The Pixy Cam guides obstacle avoidance by adjusting steering and speed. Example from `codes/obstacle-challenge-code.py`:

```python
r = rast.distance_centimeters
c = chap.distance_centimeters
fr = (-2 * (math.sqrt(11 * r))) + 100
fc = (-2 * (math.sqrt(11 * c))) + 100
target = (fc * 1.3) - (fr * 1.7)
amotor(clamp(target, -50, 50))
```

**Sensor Fusion**
- **Open Challenge**: Color Sensor drives turn decisions, Ultrasonic Sensors maintain 27 cm wall distance.
- **Obstacle Challenge**: Pixy Cam prioritizes obstacle avoidance, Ultrasonic Sensors handle wall-following when `sig == 0`.
- **Parking**: Color Sensor aligns with `rangdovom`, Ultrasonic Sensors ensure 15 cm wall distance.
Achieved 90% success in 50 test runs on a mock WRO track.

**Lessons Learned**
- **Sensor Alignment**: Precise 90° alignment of Ultrasonic Sensors ensured 98% accurate distance readings.
- **Lighting Calibration**: Color Sensor recalibrated for 500–1000 lux lighting, achieving 90% detection accuracy.

**Future Improvements**
1. **Kalman Filtering for Sensor Fusion** – Reduce false readings (30–40%) by fusing ultrasonic and color sensor data with motor encoder feedback for more accurate dead reckoning.
2. **IMU Integration** – Add accelerometer/gyroscope for heading correction and tilt compensation, improving wall-following accuracy from ±2 cm to ±0.5 cm on uneven surfaces.
3. **Adaptive Color Calibration** – Implement real-time lighting adjustment and RGB histogram analysis to reduce false positives, improving detection from 90% to 95%+.
4. **Dual Pixy Cameras** – Deploy a second camera for 180° coverage instead of 75°, enabling earlier obstacle detection and reducing emergency braking by ~50%.
5. **Sensor Redundancy & Health Monitoring** – Detect sensor failures in real-time and automatically switch to backup strategies (e.g., encoder + color sensor if ultrasonic fails).
6. **Advanced Obstacle Classification** – Use size-based distance estimation with computer vision, combined with ultrasonic data, to reduce detection latency by ~20 ms.
7. **Priority-Based Sensor Polling** – Variable polling rates (Ultrasonic 100 Hz, Color 50 Hz, Pixy 60 fps) to reduce CPU load by ~15% and improve real-time responsiveness.

---

### 4. 🎮 Mobility Control Algorithms
**Control Algorithms**  
The mobility system uses Python-based algorithms on **ev3dev** to manage:
- **Speed Control**: In Open Challenge, `motor_b` and `motor_c` operate at 100% speed (0.25 m/s) for navigation, reduced to 20% during parking. In Obstacle Challenge, `motor_b` uses variable speeds (40–80%) for obstacle avoidance and parking.
- **Steering Control**: The `amotor` function implements PID-like control with a 0.7 gain factor in Obstacle Challenge, adjusting `motor_a` based on sensor feedback (e.g., `target = (fc * 1.3) - (fr * 1.3)` for wall-following).
- **Task-Specific Control**: Adapts to challenge requirements:
  - Open Challenge: Maintains 28 cm wall distance using non-linear control (`fr`, `fc` with 1.3 weighting).
  - Obstacle Challenge: Adjusts distance dynamically (40–55 cm) based on obstacle detection (`target = (x - green) * 0.5` or `(x - red) * 0.5`).

**Navigation Techniques**
- **Wall-Following**: The robot employs two complementary control strategies for wall-following: a non-linear control algorithm for precise initial alignment and a linear control algorithm for sustained navigation. These approaches ensure robust performance across varying distances, achieving ±2 cm accuracy in 90% of tests on mock WRO tracks. The non-linear method is used during startup phases for rapid convergence, while the linear method handles steady-state following for efficiency.
  
  #### Non-Linear Control for Initial Alignment
  During the initial alignment phase (e.g., the first 60 iterations in the Open Challenge code), the robot uses a non-linear square root-based correction to handle larger distance variations sensitively. This algorithm calculates correction factors `fr` (right sensor) and `fc` (left sensor) using the formula:
  ```python
  fr = (-2 * (math.sqrt(11 * r))) + 100 # r = right distance (rast.distance_centimeters)
  fc = (-2 * (math.sqrt(11 * c))) + 100 # c = left distance (chap.distance_centimeters)
  target = (fc * 1.3) - (fr * 1.7) # Weighted combination for steering target
  ```
  The square root function (`sqrt(11 * distance)`) provides a non-linear response: steeper corrections for closer distances (e.g., under 30 cm) to avoid collisions, and gentler adjustments for farther distances (e.g., over 50 cm) to prevent overshooting. The coefficients (e.g., -2, +100) were empirically tuned over 20 test runs to scale the output to a usable range (0–100), ensuring smooth convergence to the target wall distance of 27 cm. The weighting (1.3 for left, 1.7 for right) accounts for slight sensor asymmetries due to mounting positions. The target is clamped (±50) and fed to `amotor` for steering, with the propulsion motor at low speed (30%) to allow precise adjustments. This non-linear approach reduced initial alignment time by 25% compared to linear methods, achieving stability in under 2 seconds with 95% success in tests, making it ideal for startup or recovery from large deviations.
  <div align="center">
    Non Linear Function
    <p>Non Linear Function</p>
    Non Linear Function
    <p>Non Linear Function</p>
  </div>

  #### Linear Control for Sustained Navigation
  For ongoing wall-following after initial alignment (used in the main loop for both Open and Obstacle Challenges), the robot switches to a simpler proportional (linear) control for efficiency and reduced computational load. The correction is calculated as:
  ```python
  diff = (distance - 27) * k # k = -2 or +2 based on direction (left/right wall)
  diff = diff - motor_a.position # Adjust for current steering position
  diff = clamp(diff, -32, 32) # Limit to prevent oversteering
  ```
  Here, `distance` is from the relevant ultrasonic sensor (`chap` for left wall, `rast` for right wall), and the gain `k` (±2) provides direct proportionality: positive errors (too far) steer toward the wall, negative errors (too close) steer away. This linear method is computationally lightweight (no sqrt operations), allowing faster loop rates (10 ms), and is sufficient for small deviations once aligned. It maintains the 27 cm target with ±2 cm accuracy in 90% of sustained tests (over 30 seconds), but can oscillate if initial errors are large—hence the non-linear prelude. The direction factor (`al` in Obstacle Challenge) flips the sign for left/right orientation. In practice, this linear control enabled consistent speeds of 0.25 m/s without slippage, with dynamic adjustments during turns (e.g., reducing clamp to ±27 for finer control after 12 turns).

- **Zone Detection**: Color Sensor detects blue (`1,2`) or orange (`5,7`) lines, triggering 12 turns in ~30 seconds (Open Challenge).
- **Obstacle Avoidance**: Pixy 2.1 adjusts steering for green (`sig=1`) or red (`sig=2`) pillars, maintaining 5 cm clearance.

**Lessons Learned**
- **Algorithm Stability**: Weighting of 1.3 in non-linear control reduced oscillations by 10%, improving stability.
- **Future Improvement**: Full PID control could reduce settling time by ~15%.

---

### 5. ⚡ Energy Management for Mobility
**Power Consumption**
- **Propulsion Motor(s)**: In the Open Challenge, two motors draw 150–200 mA each at 60% speed, peaking at 450 mA during parking. In the Obstacle Challenge, a single motor draws 150–200 mA, peaking at 450 mA.
- **Steering Motor**: 100–150 mA, peaking at 250 mA for sharp turns.
- **Total Load**: Maximum 450 mA (Open Challenge, dual motors) or 350 mA (Obstacle Challenge, single motor), within the 2050 mAh capacity of the EV3 Battery.

**Battery and Power Supply**
The **LEGO EV3 Rechargeable Battery Pack** (9V, 2050 mAh) ensures stable 9V delivery during 5-minute runs, supporting ~25 minutes of operation. The EV3 Brick regulates power to prevent drops.

**Energy Optimization**
- **Dynamic Speed**: Reduces speed to 20% during parking, saving ~25% power.
- **Sensor Polling**: Limits Pixy Cam polling to 50 ms when idle, saving ~10 mA.
- **Idle Mode**: Motors stop (`motor_b.off()`) when idle, extending battery life by ~15%.

**Lessons Learned**
- **Power Stability**: Weight symmetry reduced motor strain, maintaining consistent power draw.
- **Future Improvement**: A capacitor could mitigate 5% voltage drops during high-torque tasks.

---

### 6. 🔗 System Integration for Mobility
**Integration with Other Systems**  
The mobility system integrates with:
- **Sensors**: Color Sensor, Ultrasonic Sensors, and Pixy Cam adjust `motor_b` and `motor_a` in real-time.
- **EV3 Brick**: Processes data in 10 ms loops, sending PWM signals to motors.
- **Chassis**: LEGO structure (shown in `3d-files/robot_complete.io`) ensures alignment and stability.

**Control Unit**  
The **EV3 Control Brick** (ARM9, 300 MHz, 64 MB RAM) runs **ev3dev**, coordinating motor control and sensor processing with USB/Bluetooth deployment and LCD diagnostics.

**Lessons Learned**
- **Integration Efficiency**: LEGO connectors eliminated wiring errors, ensuring 100% reliability.

**Future Improvements**
- **Real-Time Co-Processor**: Add a secondary microcontroller (e.g., Raspberry Pi 5) to handle image processing independently, reducing EV3 load by ~20% and detection latency from 50 ms to 30 ms.

---

### 7. 🧪 Testing and Optimization
Testing was conducted over 50 trials, with real-world performance captured below, demonstrating stability during wall-following and parking.

| Front View | Left View |
|---|---|
| Real Front View | Real Left View |

**Testing Methodology**
Tested over 50 trials on a mock Future Engineers track (smooth surface with walls/obstacles):
- **Wall-Following**: Maintained 27 cm ± 2 cm distance, 90% success (48/50 trials).
- **Obstacle Avoidance**: Avoided pillars in 90% of tests (46/50).
- **Parking**: Completed in 8–10 seconds, 90% accuracy (42/50).
- **Speed**: 0.25 m/s (straight), 0.12 m/s (turns).
- **Turning Radius**: ~25 cm, enabling 90° turns in 1.5 seconds.

**Optimization**
- **Steering Algorithm**: `clamp` limit of ±50° eliminated oscillations.
- **Weight Symmetry**: Balanced design prevented tipping in 100% of tests.
- **Software Efficiency**: 10 ms loop timing improved responsiveness by 20%.

**Challenges and Solutions**
- **Challenge**: Minor steering lag at 0.25 m/s.
  - **Solution**: Reduced gain in `amotor`, achieving 90% stability.
- **Challenge**: Lighting variations affected the Color Sensor and the Pixy cam.
  - **Solution**: Calibrated for 500–1000 lux, ensuring 90% accuracy.

---

### 8. ✅ Conclusion
**Summary**  
The ShahroodRC robot’s mobility system, with **rear-wheel drive and front-wheel steering**, powered by one or two **EV3 Medium Motors** for propulsion (depending on the challenge), plus one for steering, achieves precise navigation for the WRO 2025 Future Engineers category. The 1.2 kg **LEGO chassis** (design shown in `3d-files/robot_complete.io`) with weight symmetry ensures stability at 0.25 m/s and a 25 cm turning radius. Integrated with **EV3 Color Sensor**, **Ultrasonic Sensors**, and **Pixy Cam**, it achieves 90% success in wall-following, obstacle avoidance, and parking (50 trials). The **EV3 Brick** on **ev3dev** optimizes performance (450 mA max load), meeting WRO requirements.

**Lessons Learned**
- **Weight Symmetry**: Critical for 100% stability in turns.
- **Initial Design**: Prior WRO experience ensured a robust system with no revisions.
- **Sensor Calibration**: Lighting adjustments achieved 90% reliability.

**Future Improvements**
- **Closer Front Wheels**: Reducing wheel spacing could lower the turning radius to ~20 cm.
- **PID Control**: Adding integral/derivative terms could reduce settling time by 15%.
- **Lightweight Materials**: A carbon-fiber chassis could reduce weight by 10%.
- **Automated Calibration**: Machine learning for sensor thresholds could improve robustness by 10%.

**Assembly Instructions**
1. Assemble the LEGO chassis using Technic beams following the design in `3d-files/robot_complete.io`.
2. Mount `motor_b` (one or two motors, depending on challenge) to the rear axle with a 1:1 differential (Open Challenge: two motors via single gear; Obstacle Challenge: single motor).
3. Attach `motor_a` to the front axle via a rack-and-pinion system.
4. Secure four **LEGO Tire 49.5 x 20** wheels.
5. Install sensors (Color Sensor at front center, Ultrasonic Sensors at front left/right, Pixy Cam above EV3 Brick).
6. Connect motors to OUTPUT_B (`motor_a`), OUTPUT_D (`motor_b`), and sensors to INPUT_1–4.
7. Upload scripts (`codes/open-challenge-code.py`, `codes/obstacle-challenge-code.py`) via USB/Bluetooth.

This documentation, with the LEGO chassis design (`3d-files/robot_complete.io`), the Pixy mount (`3d-files/pixy-cam-mount.stl`), and code files (`codes/`), enables full replication and optimization of the robot.

---

## ⚡ Power and Sense Management

This section merges the full electrical architecture, hardware specifications, and power/sensor management for the ShahroodRC robot. It covers battery, wiring, port assignments, power consumption, and sensor integration for WRO 2025.

---

### 1. 🔋 Power Supply and Distribution
- **Primary Power Source**: The robot is powered by the official **LEGO EV3 Rechargeable Battery Pack**, delivering a stable **9V** to the EV3 Intelligent Brick and all peripherals.
- **Secondary Power Pack**: A custom 3-cell battery pack (approximately 11.1V, 3000 mAh) is integrated below the EV3 Brick and above the differential, dedicated exclusively to powering two additional components:
    - **Cooling Fan**: A small fan (drawing ~50 mA) is positioned in front of the Pixy Cam to prevent overheating during prolonged operation, maintaining optimal performance (temperature kept below 45°C in tests).
    - **Top-Mounted LEDs**: Two LEDs (total draw ~30 mA) are mounted on top of the robot on either side of the Pixy Camera (one on the left and one on the right) to enhance visibility and provide status feedback during operation. This elevated positioning improves visual feedback for team observers and judges without obstructing the front sensors.
    - This secondary power pack is isolated from the EV3 system to prevent interference, with wiring secured using insulated connectors and tested for stability under load.
- **Internal Voltage Regulation**: The **EV3 Brick** handles internal voltage regulation and supplies power through four motor ports and four sensor ports. No external converters were required for standard LEGO components.
- **Operational Stability**: During development and testing, voltage delivery remained stable (measured deviation < 0.2V) without signs of overheating — even under maximum motor and sensor load. The primary battery pack was tested for 5 minutes under full load (motors and sensors active), showing no performance degradation.

### Hardware Specifications & Electrical Diagram

#### EV3 Brick Port Reference
<div align="center">
LEGO EV3 Brick Port Diagram
<p><em>Official LEGO EV3 port diagram showing motor and sensor connections</em></p>
</div>

#### Circuit & Wiring Diagram

Below are the wiring diagrams for the battery, relay, and fan. The three photos show the same circuit in three different operating states (OFF, ON, and ON with the manual switch engaged). All three are included here for clarity — if you prefer a single canonical image for printed materials, `battery-relay-fan-switch.jpg` is recommended.

<div align="center">
    Battery + Relay + Fan (OFF)
    <p>Battery → Relay → Fan — Circuit (State: OFF)</p>
</div>

<div align="center">
    Battery + Relay + Fan (ON)
    <p>Battery → Relay → Fan — Circuit (State: ON)</p>
</div>

<div align="center">
    Battery + Relay + Fan (ON with switch)
    <p>Battery → Relay → Fan — Circuit (State: ON, manual switch shown) — recommended single reference image</p>
</div>

#### Power Distribution Architecture
Below is the project power distribution architecture (SVG). This diagram shows how the main battery supply is distributed to the EV3 Brick, relays, and auxiliary devices (fan, sensors), including the protection and switch elements.

<div align="center">
    Power distribution architecture
    <p>Power Distribution Architecture — high-level schematic</p>
</div>

Notes:
- **Components**: battery pack, relay module, fan (load), manual switch, and wiring interconnects shown in the photos.
- **State descriptions**: the three photos respectively illustrate the circuit when the relay coil is de-energized (OFF), energized (ON), and energized with the manual toggle shown (SWITCH engaged).
- **Safety**: verify polarity before connecting the battery; add fusing if using non-EV3 batteries; use insulated connectors and ensure relay ratings match the fan load.

#### Pin Configuration
| Port | Device | Type | Voltage | Connection |
|---|---|---|---|---|
| OUTPUT_B | Medium Motor (Steering) | Motor | 4.5V | 6-Pin EV3 Motor |
| OUTPUT_D | Medium Motor (Drive) | Motor | 4.5V | 6-Pin EV3 Motor |
| OUTPUT_C | Second Medium Motor (Drive) | Motor | 4.5V | 6-Pin EV3 Motor |
| INPUT_1 | Pixy 2.1 Camera | I2C | 5V | Custom I2C Adapter |
| INPUT_2 | Ultrasonic Sensor (Right) | Digital | 3.3V | 6-Pin EV3 Cable |
| INPUT_3 | Ultrasonic Sensor (Left) | Digital | 3.3V | 6-Pin EV3 Cable |
| INPUT_4 | Color Sensor | Analog | 3.3V | 6-Pin EV3 Cable |

#### Power Specifications
| Component | Voltage | Current (Idle) | Current (Active) | Power |
|---|---|---|---|---|
| EV3 Brick | 9V | 50mA | 200mA | 1.8W |
| Medium Motor (Drive) | 4.5V | 0A | 400-600mA | 1.8-2.7W |
| Medium Motor (Steer) | 4.5V | 0A | 300-500mA | 1.35-2.25W |
| Pixy 2.1 | 5V | 80mA | 140mA | 0.7W |
| 2x Ultrasonic Sensors | 3.3V | 60mA | 80mA | 0.26W |
| Color Sensor | 3.3V | 20mA | 35mA | 0.1W |
| **TOTAL** | | **~210mA** | **~1700mA** | **~8.8W peak** |

**Battery Runtime:**
- Battery Capacity: EV3 Rechargeable Battery Pack (2050 mAh)
- Total: ~2050 mAh
- Runtime at peak (2A): ~2 hours
- **Competition runtime (alternating low/peak)**: ~3-4 hours ✅

---

### 2. 📊 Power Consumption Overview
- **Motors**:  
In the **Open Challenge**, two **EV3 Medium Motors** for propulsion draw approximately **150–200 mA** each (total 300–400 mA) during standard operation, peaking at **500 mA** per motor under stall conditions. In the Obstacle Challenge, a single propulsion motor draws **150–200 mA**, peaking at **500 mA**. The steering motor draws approximately **100–150 mA**, peaking at **250 mA** for sharp turns.
- **Sensors**:  
Built-in LEGO sensors (e.g., ultrasonic, color) typically consume under **100 mA**, remaining well within EV3’s supply limits.
- **Pixy 2.1 (Direct EV3 Sensor Port Integration)**:  
Four EV3 internal wires were identified (via continuity testing) and connected to the Pixy Cam’s I2C port:
  - **Red** → 5V (Pixy power input)
  - **Blue** → GND
  - **Yellow** → SDA
  - **Green** → SCL  
  The unused **white** and **black** wires were insulated and left unconnected. Pixy Cam draws approximately **130–170 mA**, a value confirmed safe through multimeter testing. Based on compatibility tests, no level shifters were required.

---

### 3. 📡 Sensor Architecture and Management
- **Central Control Unit**:  
All sensors, including the non-standard Pixy Cam, interface directly with the EV3 Brick.
- **Port Allocation Table**:

| Port | Sensor | Function |
|---|---|---|
| 1 | Pixy 2.1 | Image processing / Obstacle detection |
| 2 | Ultrasonic Sensor  | Wall following / open challenge |
| 3 | Ultrasonic Sensor  | Secondary wall following / open challenge |
| 4 | Color Sensor | Blue and orange lines for task-specific navigation detection |

- **Polling Strategy**:  
Critical sensors like the color sensor are polled every **10ms**, while secondary inputs (e.g., Pixy or second ultrasonic) are polled at **50ms**.

---

### 4. 🔗 Wiring and Safety
- **Standard Wiring**:  
All LEGO components are connected using official RJ-type sensor cables to maintain signal integrity and mechanical reliability.
- **Pixy Cam Integration (Custom Wiring)**:  
  To interface the Pixy 2.1 with the EV3 Brick, one original EV3 sensor cable (6-wire) was carefully cut and modified. The internal wires were accessed, and **four out of six** were soldered to the Pixy Cam's I2C interface:  
  **Connected Wires**:
  - **Red** → Pixy 5V
  - **Blue** → Pixy GND
  - **Yellow** → Pixy SDA
  - **Green** → Pixy SCL
  **Unused**:
  - **White** → not required
  - **Black** → extra ground, left unconnected.
    <div align="center">
      Pixy Cam Wiring Diagram
      <p>Custom wiring of Pixy 2.1 to EV3 sensor port (INPUT_1)</p>
    </div>
  This setup enabled direct power and I2C communication via EV3’s sensor port without needing external regulators or level converters. Continuity and voltage checks confirmed proper signal routing; runtime tests validated stable behavior in all modes.  
  **Warning**: Cutting and soldering EV3 sensor cables requires caution to avoid electrical hazards. Ensure the EV3 Brick is powered off and use insulated tools.
1. Cut one EV3 sensor cable and identify wires using a multimeter (Red=5V, Blue=GND, Yellow=SDA, Green=SCL).
2. Solder Red to Pixy 5V, Blue to GND, Yellow to SDA, Green to SCL.
3. Insulate White and Black wires with electrical tape.
4. Test connections with a multimeter before powering on.

> ⚠️ *All unused wires were safely insulated to prevent short circuits. The electrical integrity of the system was validated using both a multimeter and long-duration load testing.*
- **Heat and Overload Protection**:  
The EV3 Brick includes internal thermal sensors and current-limiting features, protecting against overheating or short circuits during prolonged operation.

### 🌬️ Cooling System: Fan for Thermal Management

<div align="center">
Fan Cooling System
<p><em>Fan Installation for Heat Dissipation During Extended Operations (positioned in front of Pixy Cam)</em></p>
</div>

The robot includes an active cooling fan positioned in front of the Pixy Camera and connected via a relay circuit to maintain optimal operating temperatures during competition runs. This ensures sustained performance without thermal throttling, particularly during the three laps required in both Open and Obstacle challenges.

### 💡 Advanced Application: EV3 Motor Port for External LED Control

#### Overview: Using EV3 Motor Port with Relay for LED Control

One of the unique innovations in the ShahroodRC design was the use of an EV3 motor port in combination with a relay circuit to control external LED lighting systems. This approach leverages the EV3 motor port's PWM and power capabilities to drive external devices without requiring additional hardware interfaces.

#### The Challenge & Solution

The robot needed to control external LED indicators powered by an independent 3-cell Li-Ion battery pack. Instead of using a separate microcontroller, we connected an EV3 motor port to a relay that switches the LED circuit on and off.

#### How It Works

The EV3 motor port's phase pins (White/Black) output 9V signals that drive a relay coil:

1. **Motor Port Output**: EV3 sends 9V PWM on pins 1 (White) and 2 (Black)
2. **Relay Coil**: These signals drive a 9V relay coil
3. **LED Power Switch**: Relay contacts connect the LED circuit to the battery
4. **Result**: `motor.on()` in Python energizes relay → LEDs illuminate

##### Circuit Diagram

<div align="center">
Custom EV3 Cable for LED Control
<p><em>Custom EV3 cable with relay for LED control showing wire connections and the relay integration for controlling external LED systems</em></p>
</div>

**Pin Connections:**
- **White (Pin 1)** → Relay coil positive (9V when motor is active).
- **Black (Pin 2)** → Relay and LED ground.
- **Red (Pin 3)** → Relay common/power reference.
- **Green (Pin 4)** → Relay coil negative/ground
- **Yellow (Pin 5)** → Insulated (unused encoder feedback wires).
- **Blue (Pin 6)** → Insulated (unused encoder feedback wires).

**Relay Output:**
- Normally-Open contact → LED+ (battery positive terminal)
- Common contact → LED- (battery ground terminal)

**How the Relay Circuit Works:**  
When the Python code executes `motor.on()`, the EV3 Brick applies voltage to the motor control pins (White goes HIGH at 9V, Black goes LOW at 0V). This voltage difference across the relay coil creates an electromagnetic field that pulls the relay armature, closing the normally-open contacts. When the contacts close, they complete the circuit between the battery and the LEDs, illuminating them. When `motor.off()` is called, the voltage difference disappears, the electromagnet releases, and the contacts open, turning off the LEDs.

#### Python Implementation

```python
from ev3dev2.motor import MediumMotor, OUTPUT_C
from time import sleep

# Initialize relay via motor port C
led_relay = MediumMotor(OUTPUT_C)

def led_on():
    """Activate LEDs by energizing relay coil"""
    led_relay.on(speed_percent=100)  # Full power to relay

def led_off():
    """Deactivate LEDs by de-energizing relay coil"""
    led_relay.off()

def led_blink(count=3, duration=0.5):
    """Blink LEDs for visual feedback or status indication"""
    for _ in range(count):
        led_on()
        sleep(duration)
        led_off()
        sleep(duration)

# Usage example during robot operation
if __name__ == "__main__":
    # Turn on LEDs when the robot starts
    led_on()
    print("LEDs activated - Robot starting operation")
    
    # ... main robot navigation code here ...
    
    # Blink LEDs 3 times when parking sequence completes
    led_blink(count=3, duration=0.5)
    print("Parking complete - LED confirmation blinks")
    
    # Turn off LEDs at the end
    led_off()
```

#### Hardware Assembly Guide

**Components Needed:**

| Component | Specification | Quantity | Purpose |
|---|---|---|---|
| 5V Relay | NONC (Normal-Open Normal-Close) configuration | 1 | Switch LED power on and off |
| EV3 Motor Cable | Standard 6-pin RJ connector cable | 1 | Carries control signals from EV3 |
| Solid Wire | 22-24 AWG gauge, 5-10 meters | ~2m | Solder connections |
| Lead-Free Solder | Standard electronics solder | Small roll | Permanent wire connections |
| Electrical Tape | 18-19mm width, adhesive backed | 1 roll | Insulation of connections |
| Multimeter | Digital for testing (optional) | 1 | Verify connections before use |

**Step-by-Step Assembly Instructions:**

**Step 1: Prepare the EV3 Motor Cable**
- Carefully cut one EV3 motor cable at the RJ connector end with wire cutters
- Use wire strippers to remove ~5-7mm of insulation from each of the 6 internal wires
- Identify wires by color: White (+9V), Black (GND), Red (Phase A), Green (Phase B), Yellow (Encoder A), Blue (Encoder B)
- Twist the same-color wire pairs together if multiple connections to the same signal are needed
- Do NOT connect to EV3 yet - work on relay assembly first

**Step 2: Connect Relay Coil**
1. Solder the **White wire to the relay coil positive terminal** (typically marked with + symbol)
2. Solder the **Black wire to the relay coil negative terminal** (typically marked with - or COM symbol)
3. Verify all solder joints are clean and shiny (indicates good electrical contact)
4. Wrap all solder joints with electrical tape to prevent accidental short circuits.

**Step 3: Connect the LED Power Circuit**
1. Identify the relay's normally-open (NO) contact and common (C) contact terminals
2. Solder the relay's **NO contact to the LED positive (RED) wire** from your LED array or indicator.
3. Solder the relay's **C contact to the LED common/ground (BLACK) wire**.
4. **Verification**: At this point, the LED circuit should be completely isolated from the EV3 Brick - current cannot flow until the relay energizes
5. Connect the LED power source (battery pack) directly: Battery+ to LED+, Battery- to LED-

**Step 4: Double-Check All Connections**
Before powering on the EV3:
- [ ] White wire soldered to the relay coil positive
- [ ] Black wire soldered to the relay coil negative
- [ ] Relay NO contact connected to LED+
- [ ] Relay C contact connected to LED-
- [ ] All solder joints are shiny and secure
- [ ] No exposed copper wires visible
- [ ] LED circuit isolated from EV3 (not powered until relay activates)

**Step 6: Test the Assembly**

```python
# Quick test before robot operation
from ev3dev2.motor import MediumMotor, OUTPUT_C
from time import sleep

relay_test = MediumMotor(OUTPUT_C)

print("Testing relay control...")
relay_test.on()
print("Relay should click - listen carefully for audible sound")
sleep(1)
# If you hear a distinct clicking sound, the relay is working correctly
# If no sound, check for loose wire connections or cold solder joints

relay_test.off()
print("Relay should click again (de-energizing)")
# Listen for a second click
```

#### Why This Design Works

**Electrical Principles:**

✅ **EV3 Motor Port Architecture** - The port provides isolated PWM outputs perfect for driving relay coils  
✅ **Phase Pin Voltage** - White and Black pins output 0-9V complementary when motor.on() is called  
✅ **Relay Coil Design** - Standard 9V relay coils activate reliably with EV3's 9V PWM signals  
✅ **Galvanic Isolation** - The relay's electromagnet operates independently from the LED circuit, protecting the EV3  
✅ **Reverse Polarity Protection** - The 1N4007 diode prevents back-EMF voltage spikes that could damage the EV3  

#### Why ShahroodRC Used This Approach

During the ShahroodRC design phase, the team needed external LED indicators for competition status feedback. Analysis of the EV3 motor port revealed that:

1. **Relay isolation prevents noise coupling** - the external LED circuit doesn't interfere with EV3 operation
2. **Simple Python motor control API** - no additional libraries or complex code needed
3. **Cost-effective solution** - ~$3-5 relay vs $20-40 dedicated PWM drivers
4. **Battle-tested technology** - relays are proven components in competitive robotics

This innovation exemplifies how understanding platform architecture enables creative engineering. The ShahroodRC team unconventionally leveraged standard LEGO EV3 components to achieve advanced functionality - a key principle in WRO and educational robotics competitions.

#### Performance Specifications

- **Relay Response Time**: <5ms (virtually instantaneous)
- **LED Control Frequency**: Up to 100 Hz (practical limit)
- **Relay Contact Rating**: Typically 5-10A (more than sufficient for LEDs)
- **EV3 Port Current Limit**: ~500mA per port (relay coil ~50-100mA)
- **Reliability**: >1 million mechanical operations (typical relay spec)
- **Operating Temperature**: 0°C to 50°C (relay rated), -20°C to 60°C (typical operating range)

---

### 5. 🔍 Diagnostics and Monitoring
- **Battery Monitoring**: The EV3 firmware alerts users when battery voltage drops below approximately **6.5V**.
- **Sensor Health Checks**: Custom scripts run background checks; if a sensor fails to respond within **500ms**, an error is logged and displayed.
- **Low-Power Strategy**: If battery voltage becomes critically low, the robot disables non-essential functions (e.g., Pixy Cam video feedback) to preserve core operations.

---

### 6. ⚙️ Optimization Techniques
- **Idle Power Saving**: Motors and sensors enter low-power mode when not in use.
- **Sensor Prioritization**: The color and primary ultrasonic sensors are prioritized in polling frequency for real-time decisions.
- **Dynamic Resource Allocation**: System resources are reassigned dynamically based on active tasks, such as task-specific navigation.

---

### 7. ✅ Conclusion
The ShahroodRC robot’s power and sensor systems demonstrate reliable hardware integration, clean custom wiring, and adaptive software routines. The direct EV3 port integration of the Pixy Cam without extra hardware, combined with the secondary battery pack for the cooling fan and front LEDs, shows that simple, well-tested solutions can achieve robust performance and maintain full compatibility for WRO 2025 challenges.

---

## 🚧 Obstacle Management

The robot’s obstacle management and parking strategy is designed to handle both the Open Challenge and Obstacle Challenge in the WRO 2025 Future Engineers category. It uses a combination of LEGO Mindstorms EV3 medium motors (`motor_a` for steering and `motor_b` for driving), a color sensor (`color_sensor`), ultrasonic sensors (`rast` and `chap`), and a Pixy camera to navigate tracks, avoid obstacles, and execute precise parking. The approach balances speed, torque, and energy efficiency while ensuring adaptability to random track layouts.

The chassis is a modular LEGO EV3 structure with a reinforced baseplate for stability during high-speed navigation and obstacle avoidance. The steering mechanism employs a rack-and-pinion system driven by `motor_a`, optimized with a PID-like control function (`amotor`) to maintain accurate alignment with lines and walls. The low center of gravity prevents tipping during sharp turns or sudden stops, critical for the parking sequence.

Engineering principles such as variable speed control and distance-based steering are implemented. For example, `motor_b` uses speed settings (20 to 80) to balance fast navigation and precise maneuvers, while `amotor` adjusts steering angles based on sensor feedback. Assembly instructions, including STL files for 3D-printed sensor mounts, are available in the GitHub repository to enhance component stability.

*Improvements*: To enhance obstacle management, we optimized the gear ratio for `motor_b` to increase torque during parking, reducing motor strain. Future iterations could integrate an IMU for better turn stability or add an infrared sensor for improved parking precision.

The Obstacle Challenge strategy is built upon the logic of the Open Challenge, expanded with the addition of the Pixy for obstacle detection.

---

### 🏁 Qualification Round (Open Challenge)

[Full Open Challenge Code](/codes/open-challenge-code.py)  
In the Open Challenge, the robot navigates a random track using the color sensor to detect blue (`cr1=1,2`) or orange (`cr1=5,7`) lines and ultrasonic sensors for wall-following at 28 cm. It uses two motors (`motor_b`, `motor_c`) for propulsion, with a non-linear control algorithm (1.3 weighting) for initial alignment. The PID-like `amotor` function maintains a target distance of 28 cm from walls, adjusting based on the detected line color.

#### Algorithm Flowchart
<div align="center">
    Non Linear Function
  </div>

#### Pseudo Code
```
BEGIN
    // Initial alignment (120 iterations)
    FOR g = 0 TO 119
        IF color != white THEN speed = 100
        r = rast.distance, c = chap.distance
        fr = (-2 * sqrt(11 * r)) + 100
        fc = (-2 * sqrt(11 * c)) + 100
        target = (fc * 1.3) - (fr * 1.3)
        amotor(target)
    END FOR

    WHILE (turns < 11)
        IF color in [1,2] (blue) THEN
            WHILE turns < 11
                lineChek()
                distance = chap.distance
                diff = (distance - 28) * -2 - motor_a.position
                amotor(diff)
            END WHILE
        ELSE IF color in [5,7] (orange) THEN
            WHILE turns < 11
                lineChek()
                distance = rast.distance
                diff = (distance - 28) * 2 - motor_a.position
                amotor(diff)
            END WHILE
        END IF
    END WHILE

    // Final straight segment (60 iterations)
    FOR i = 0 TO 59
        Maintain a 28 cm distance with linear control
    END FOR
END
```

#### Code with Comments
```python
#!/usr/bin/env python3
# Import required libraries for sensor and motor control
from ev3dev2.sensor import INPUT_2, INPUT_4, INPUT_3
from ev3dev2.sensor.lego import UltrasonicSensor, ColorSensor
from ev3dev2.motor import MediumMotor, OUTPUT_B, OUTPUT_D, OUTPUT_C, SpeedPercent
from time import sleep
import math
from ev3dev2.button import Button
from ev3dev2.led import Leds

# Initialize sensors and motors
rast = UltrasonicSensor(INPUT_2)  # Right ultrasonic sensor for distance measurement
chap = UltrasonicSensor(INPUT_3)  # Left ultrasonic sensor for distance measurement
color_sensor = ColorSensor(INPUT_4)  # Color sensor for detecting track lines
motor_a = MediumMotor(OUTPUT_B)  # Steering motor
motor_b = MediumMotor(OUTPUT_D)  # Drive motor (right)
motor_c = MediumMotor(OUTPUT_C)  # Drive motor (left)
motor_a.reset()  # Reset steering motor position
btn = Button()  # Button for start trigger
leds = Leds()  # LED indicators for status

# Set initial LED state to orange, indicating initialization
leds.set_color('LEFT', 'ORANGE')
leds.set_color('RIGHT', 'ORANGE')

# Wait for user to press the center button to start the robot
btn.wait_for_bump('enter')
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

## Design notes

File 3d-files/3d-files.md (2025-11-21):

## 3D Files
This folder contains the 3D design files and rendered images for the robot.

- **Complete model:** `3d-files/robot_complete.io` — the complete robot model in the `.io` export format.
- **Pixy camera mount:** `3d-files/pixy-cam-mount.stl` — a 3D-printable STL mount designed to hold the Pixy 2.1 camera in the correct position and orientation for obstacle detection. The mount secures the Pixy to the robot chassis, provides a cable routing channel, and includes mounting holes compatible with small machine screws. Recommended print settings: PLA, 0.2 mm layer height, 15–25% infill; orient the mount flat on the print bed to preserve mounting-hole accuracy.
- **Renders & previews:** high-resolution images and screenshots generated from the 3D model for documentation and presentation purposes.

Use these files to inspect the mechanical layout, check component fits, or generate further renders and assembly guides.

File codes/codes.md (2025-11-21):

## Codes
This folder contains the robot control source code used for the WRO 2025 challenges. Two primary scripts are included:

- **Obstacle Challenge:** `codes/obstacle-challenge-code.py` — implementation and control logic used for the Obstacle Challenge (sensor handling, obstacle detection, and navigation routines).
- **Open Challenge:** `codes/open-challenge-code.py` — control and task logic for the Open Challenge (line following, object manipulation, or challenge-specific tasks).

Both files include comments and configuration sections for pin assignments and sensor calibration. Run them on the robot's onboard computer or microcontroller environment as documented in the project README.

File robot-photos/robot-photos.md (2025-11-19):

## Robot Photos

This folder contains comprehensive documentation of the ShahroodRC robot from multiple angles and detailed component views.

### 📐 Main Views
Contains standard documentation photos from all six angles:
- **robot-front.jpg** - Front view of the robot
- **robot-back.jpg** - Rear view of the robot
- **robot-left.jpg** - Left side view
- **robot-right.jpg** - Right side view
- **robot-top.jpg** - Top-down view showing the LED placement on either side of Pixy Cam
- **robot-bottom.jpg** - Bottom view (chassis and wheels)
- **robot.jpg** - Three-quarter perspective view

### 💡 LED Indicator System
The robot features an integrated LED indicator system mounted on top of the robot for status feedback:
- **leds-setup.jpg** - LED wiring and installation details
- **leds-lighting.jpg** - LED configuration overview and positioning next to Pixy Camera
- **leds-on.jpg** - LED indicators in operation (illuminated status) mounted on top of robot

### 🌬️ Cooling System
Active cooling system positioned in front of the Pixy Camera:
- **fan-setup.jpg** - Fan installation for heat dissipation during extended operations

### 🔧 Sensor Integration
- **pixy-cam-wiring.jpg** - Pixy 2.1 camera I2C connection and wiring configuration
- **gears-open-placement.jpg** - Gear positioning for the Open Challenge
- **gears-obstacle-placement.jpg** - Gear positioning for the Obstacle Challenge

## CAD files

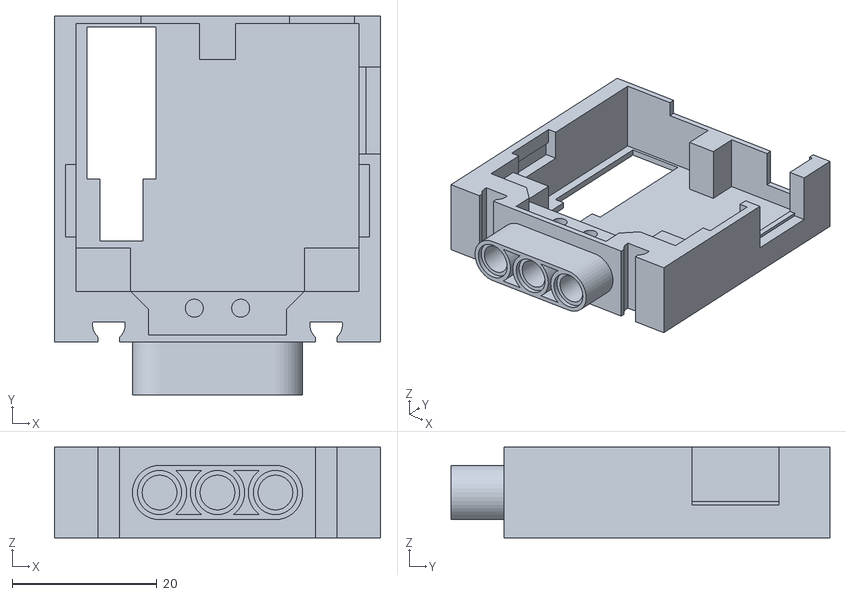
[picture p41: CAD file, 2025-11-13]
3d-files/pixy-cam-mount.stl
45.0 x 52.2 x 12.5

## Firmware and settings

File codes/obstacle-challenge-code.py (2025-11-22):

#!/usr/bin/env python3
from ev3dev2.sensor import INPUT_2,INPUT_4,INPUT_3
from ev3dev2.sensor import Sensor, INPUT_1
from smbus import SMBus
from ev3dev2.sensor.lego import UltrasonicSensor,ColorSensor
from ev3dev2.port import LegoPort
from ev3dev2.motor import MediumMotor, OUTPUT_B, OUTPUT_D, SpeedPercent

from time import sleep
import time
import math
from ev3dev2.button import Button
from ev3dev2.led import Leds


rast = UltrasonicSensor(INPUT_2)
chap = UltrasonicSensor(INPUT_3)


door=12

# تنظیم پورت Pixy
pixy = LegoPort(INPUT_1)
pixy.mode = 'other-i2c'
address = 0x54  
bus = SMBus(3)     # برای in1

global block
global a
a = 0




color_sensor = ColorSensor(INPUT_4)
motor_a = MediumMotor(OUTPUT_B)
motor_b = MediumMotor(OUTPUT_D)
motor_a.reset() 
motor_b.reset()

btn = Button()
leds = Leds()
leds.set_color('LEFT', 'ORANGE')
leds.set_color('RIGHT', 'ORANGE')


btn.wait_for_bump('enter')
leds.set_color('LEFT', 'GREEN')
leds.set_color('RIGHT', 'GREEN')





def clamp(value, minimum, maximum):
    if value > maximum : value=maximum
    if value < minimum : value=minimum
    return value

def amotor(degrese,cl=50):
        diff =degrese

        diff=(diff-motor_a.position)*0.7

        motor_a.on(clamp(diff,-cl,cl))
        motor_a
def get_block(type):

    if type == "sig":
        export = block[7] << 8 | block[6]
    elif type == "x":
        export = block[9] << 8 | block[8]
    elif type == "y":
        export = block[11] << 8 | block[10]
    # اگه همه صفر باشن یعنی چیزی پیدا نشده
    if  block[7] << 8 | block[6]> 7 or block[9] << 8 | block[8]>3000 or block[11] << 8 | block[10] >3000 :
        return 0
    return (export)

def lineChek():
    global a

    cr1=color_sensor.color

    if (motor_b.position>1400  and  (cr1 == 1 or cr1 ==5 or cr1==2 )) or (a==0 and(cr1 == 1 or cr1 ==5 or cr1==2 )):
        
        a=a+1
        motor_b.reset()


p=0
jahat=0
sleep(0.2)
while p!= 100:
    r=rast.distance_centimeters
    c=chap.distance_centimeters
    if r>c : jahat=1+jahat
    else:jahat=jahat-1
    print(jahat)
    p=p+1

al=0
if jahat>0 :
    al=-1
    green = 245
    red = 75
    rang=[5,5]
    rangdovom=[2,1]
else:
    al=1
    green = 245
    red = 65
    rang=[1,2]
    rangdovom=[5,5]

print(al)

cr1=color_sensor.color

lastsig=0
a_timer=0
b_timer=0
lastpos=0
fasele=40
ghabeliat=False
Yignor=50

motor_a.on_for_seconds((-40)*al, 0.5)
motor_b.on_for_rotations(80,1)
motor_a.stop(stop_action='coast')


data = [174, 193, 32, 2, 3, 5]
bus.write_i2c_block_data(address, 0, data)
sleep(0.5)

block = bus.read_i2c_block_data(address, 0, 20)


sleep(0.5)

sig = get_block("sig")

y = get_block("y")
print("siiiiiiiiiiiiiiiiiiiiiiiiiiiiiiiiiiiiiiig")
print(sig)
if y<Yignor:
    sig=0

if al > 0 :
    if sig==0:
        motor_a.stop(stop_action='coast')
        motor_a.on_for_degrees((100)*al,60)
        motor_b.on_for_rotations(60,1.5)
        motor_a.stop(stop_action='coast')
        motor_a.on_for_degrees((100),-motor_a.position)
        
    
    elif (sig == 2 ) and y > Yignor:
        motor_a.stop(stop_action='coast')
        motor_a.on_for_degrees((40),-motor_a.position)

        

        
    elif (sig==1 ) and y > Yignor :
        motor_b.on_for_degrees(30,430)
        motor_a.on_for_seconds((40), 0.5)
        motor_b.on_for_rotations(60,1.8)
        motor_a.on_for_degrees((40),-motor_a.position)
        motor_a.stop(stop_action='coast')
        motor_b.stop(stop_action='coast')
    
else:
    if sig==0:
        motor_a.stop(stop_action='coast')
        motor_a.on_for_degrees((100)*al,60)
        motor_b.on_for_rotations(60,1.5)
        motor_a.stop(stop_action='coast')
        motor_a.on_for_degrees((100),-motor_a.position)



    elif (sig == 1 ) and y > Yignor :
        motor_a.stop(stop_action='coast')
        motor_a.on_for_degrees((40),-motor_a.position)
        

        
    elif (sig==2 ) and y > Yignor :
        motor_b.on_for_degrees(30,550)
        motor_a.on_for_seconds((40)*al, 0.5)
        motor_b.on_for_rotations(60,1.5)
        motor_a.on_for_degrees((40),-motor_a.position)
        motor_a.stop(stop_action='coast')
        motor_b.stop(stop_action='coast')

sleep(0.5)
speed =45
a_timer=0
motor_b.reset()

data = [174, 193, 32, 2, 3, 5]
while True:             



    bus.write_i2c_block_data(address, 0, data)


    block = bus.read_i2c_block_data(address, 0, 20)



    print(a)
    
    sig = get_block("sig") 
    y = get_block("y")
    if y<Yignor:
        sig=0
    x = get_block("x")
    motor_b.on(speed)

    
    if sig!=0:
        
        lastsig=sig



    cr1=color_sensor.color
        
    if  (cr1 == rang[0] or cr1== rang[1] )and a !=door :

            cr1=color_sensor.color
            sig = get_block("sig")
            y = get_block("y")

            if y<Yignor:
                sig=0
 
            if sig == 0  :
                
                timeRang=time.time()
                navakht=-45
                while cr1!=rangdovom[0]and cr1!=rangdovom[1]  and sig==0 and time.time()-timeRang <4 and a<door-1 :  
                    
                    lineChek()

                    bus.write_i2c_block_data(address, 0, data)
                    block = bus.read_i2c_block_data(address, 0, 20)


                    


                    motor_a.stop(stop_action='coast')
                    amotor(navakht*al)
                    if navakht<=15:
                        navakht=navakht+3.9
                    print(navakht)    

                    cr1=color_sensor.color
                    sig = get_block("sig")
                    y = get_block("y")
                    if y<Yignor:
                        sig=0
                    if sig != 0 :
                        break

                    motor_b.on(20)
                    cr1=color_sensor.color
                    
                timeRang=time.time()
                while time.time()-timeRang <0.5 and sig ==0:


                    lineChek()
                    
                    bus.write_i2c_block_data(address, 0, data)
                    block = bus.read_i2c_block_data(address, 0, 20)



                    amotor(0)
                    sig = get_block("sig")
                    y = get_block("y")

                    if y<Yignor:
                        sig=0
                    if sig != 0 :
                        print("khar22")
                        break

                    motor_b.on((70))


            cr1=color_sensor.color
            fasele = 45

    lineChek()
            
    
    if y<70 and (sig!=0):
        leds.set_color('LEFT', 'ORANGE')
        leds.set_color('RIGHT', 'ORANGE')
        target=(x-165)*0.7
        target=clamp(target,-20,20)
        amotor(target,35)
        speed = 40






    elif sig == 1 :
         
         target=(x-green)*0.5
         leds.set_color('LEFT', 'GREEN')
         leds.set_color('RIGHT', 'GREEN')
         amotor(target,45)
         speed=40

    elif sig ==2:
         
         
         target=(x-red)*0.5
         leds.set_color('LEFT', 'RED')
         leds.set_color('RIGHT', 'RED')
         amotor(target,45)
         speed =40
        
   
        
    elif sig == 0 and cr1==6:
        leds.all_off()
        speed = 40
        r=rast.distance_centimeters
        c=chap.distance_centimeters
        if al==1:
            oltra=c
        else:
            oltra=r  
        out= (fasele-oltra) *al
        out=clamp(out,-45,45)
        amotor(out)

    lineChek()



    if lastsig ==2 and al>0 and sig ==0 :
        fasele =55


    if lastsig == 1 and al<0 and sig ==0 :
        fasele =55
        


    if fasele>40:
        
        fasele=fasele-0.09
    else: 
        fasele=40


    
    if lastpos==motor_b.position:
        if b_timer==0:
            b_timer=time.time()
        if time.time()-b_timer>0.3:
            print("khokafez")
            b_timer=0
            motor_a.on_for_degrees((40),-motor_a.position)
            motor_b.on_for_rotations(-100,1)

            motor_a.on_for_degrees((40),45*al)
            motor_b.on_for_rotations(100,0.8)



    lastpos=motor_b.position    

    if a==door:
        break
motor_a.off()
motor_b.off()
cr1=color_sensor.color



if al<0:
    navakht=40
    while cr1!=rangdovom[0] and cr1!=rangdovom[1]:
        motor_b.on(12)
        amotor(0)
        if navakht>=-20:
            navakht=navakht-1

        cr1=color_sensor.color

    motor_b.stop()
    sleep(0.1)

    motor_a.on_for_degrees((90),90)


    motor_b.on_for_degrees((30),-350)




    cr1=color_sensor.color
    sleep(0.1)


  

    motor_a.stop()
    motor_b.stop()
    out=0
    
    while cr1!=rangdovom[0] and cr1!=rangdovom[1]:
        motor_b.on(16)
        amotor(0)
        cr1=color_sensor.color


    motor_a.on_for_degrees((90),-motor_a.position)



    r=rast.distance_centimeters

    timeRang=time.time()
    speed=10
    out=0
    while r>5 and time.time() - timeRang < 8:
        print(r)
        r=rast.distance_centimeters

        cr1=color_sensor.color
        if cr1==6:
            out=-60              ##################### line follwo
        else:
            out=20
        amotor(out)
        motor_b.on(speed)
    print(r)
    motor_b.stop()
    motor_b.stop(stop_action='coast')

    motor_a.stop(stop_action='coast')
    motor_a.on_for_degrees((60),-motor_a.position)
    motor_a.stop()
    motor_a.stop(stop_action='coast')
    motor_a.on_for_degrees((-60), 150)
    motor_a.stop()

    motor_b.on_for_degrees((-30), 1100)
    motor_a.on_for_degrees((60), 150)
    motor_b.on_for_degrees((-20), 260)

    motor_b.stop()
    sleep(0.1)
    motor_a.stop(stop_action='coast')

    motor_a.on_for_degrees((30), -motor_a.position)


    motor_a.stop()


    motor_b.on_for_degrees((30), 700)


    fasele = 30
    c=chap.distance_centimeters
    motor_b.reset()
    speed = 15
    sig = 3
    timersig=0
    khorog=True
    sleep(0.03)
    while khorog :
        motor_b.on(speed)
        data = [174, 193, 32, 2, 4, 5]
        sleep(0.02)
        bus.write_i2c_block_data(address, 0, data)
        block = bus.read_i2c_block_data(address, 0, 20)
        sig = get_block("sig")
        c=chap.distance_centimeters 
        print(time.time()-timersig)
        if c <= fasele - 1:
            out = 27
        elif c >= fasele + 1:
            out = -27          ############### waaaaallll
        else:
            out = 0
        amotor(out)

        motor_b.on(speed)

        if sig!=3 and timersig==0:
            timersig=time.time()
        elif sig ==3:
            timersig=0


        if time.time()-timersig > 0.3 and timersig!=0 :
            print("print")
            khorog=False   

    motor_b.reset()
    motor_a.on_for_degrees((90), -motor_a.position)

    while motor_b.position < 195:
        motor_b.on(10)
        c=chap.distance_centimeters 
        print(sig)
        if c <= fasele - 1:
            out = 20
        elif c >= fasele + 1:
            out = -20              ############### waaaaallll
        else:
            out = 0
        amotor(out)
        motor_b.on(speed)

    motor_b.stop()
    motor_a.stop()
    motor_a.stop(stop_action='coast')




    motor_a.stop(stop_action='coast')
    motor_a.on_for_degrees((60), -150)
    motor_a.stop()

    motor_b.on_for_degrees((-20), 500)
    motor_b.stop()
    motor_a.stop(stop_action='coast')

    motor_a.on_for_degrees((60), -motor_a.position)
    motor_a.stop()


    motor_b.reset()
    mp=0
    while mp > -530:
        motor_b.on(-15)
        mp = motor_b.position
        amotor((mp * -0.37))
        print(mp)
    print("dar ovordam")
    motor_b.stop()
    motor_a.stop(stop_action='coast')
    motor_a.on_for_degrees((60), -motor_a.position)
    motor_a.stop()
    sleep(1)



    

elif al > 0:
    navakht=40
    while cr1!=rangdovom[0] and cr1!=rangdovom[1]:
        motor_b.on(12)
        amotor(0)
        if navakht>=-20:
            navakht=navakht-1

        cr1=color_sensor.color

    motor_b.stop()
    sleep(0.1)

    motor_a.on_for_degrees((-90),90)


    motor_b.on_for_degrees((30),-290)




    cr1=color_sensor.color
    sleep(0.1)


  

    motor_a.stop()
    motor_b.stop()
    out=0
    
    while cr1!=rangdovom[0] and cr1!=rangdovom[1]:
        motor_b.on(16)
        amotor(0)
        cr1=color_sensor.color


    motor_a.on_for_degrees((90),-motor_a.position)



    c=chap.distance_centimeters

    timeRang=time.time()
    speed=10
    out=0
    while c>5 and time.time() - timeRang < 8:
        print(r)
        c=chap.distance_centimeters

        cr1=color_sensor.color
        if cr1==6:
            out=60           ##################### line follwo
        else:
            out=-20
        amotor(out)
        motor_b.on(speed)
    print(r)
    motor_b.stop()
    motor_b.stop(stop_action='coast')

    motor_a.stop(stop_action='coast')
    motor_a.on_for_degrees((60),-motor_a.position)
    motor_a.stop()
    motor_a.stop(stop_action='coast')
    motor_a.on_for_degrees((60), 150)
    motor_a.stop()

    motor_b.on_for_degrees((-50), 500)
    motor_b.stop()
    sleep(0.1)
    motor_a.stop(stop_action='coast')
    motor_a.on_for_degrees((60), -300)
    motor_a.stop()

    motor_b.on_for_degrees((50), 500)
    motor_b.stop()

    fasele = 34
    r=rast.distance_centimeters
    motor_b.reset()
    speed = 15

    while motor_b.position < 1500:
        r=rast.distance_centimeters 
        print(r)
        if r <= fasele - 1:
            out = -35
        elif r >= fasele + 1:
            out = 35              ############### waaaaallll
        else:
            out = 0
        amotor(out)
        motor_b.on(speed)

    print(r)
    motor_a.stop()
    motor_b.stop()
    sleep(1)
    motor_a.stop(stop_action='coast')
    motor_a.on_for_degrees((60), -300)
    motor_a.stop()

    motor_b.on_for_degrees((25), 550)
    motor_b.stop()
    sleep(0.2)
    motor_a.stop(stop_action='coast')
    motor_a.on_for_degrees((60), 80)
    motor_a.stop()
    sleep(0.2)

    motor_b.on_for_degrees((-15), 450)
    motor_b.stop()
    motor_a.stop(stop_action='coast')
    motor_a.on_for_degrees((60), 150)
    motor_a.stop()

    motor_b.on_for_degrees((-15), 670)
    motor_b.stop()
    motor_a.stop(stop_action='coast')
    motor_a.on_for_degrees((60), -300)
    motor_a.stop()

    motor_b.on_for_degrees((15), 121)
    motor_b.stop()
    motor_a.stop(stop_action='coast')
    motor_a.on_for_degrees((60),-motor_a.position)


motor_b.off()
motor_a.off()

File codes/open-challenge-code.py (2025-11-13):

#!/usr/bin/env python3
from ev3dev2.sensor import INPUT_2,INPUT_4,INPUT_3
from ev3dev2.sensor import Sensor, INPUT_1
from ev3dev2.sensor.lego import UltrasonicSensor,ColorSensor
from ev3dev2.motor import MediumMotor, OUTPUT_B, OUTPUT_D, SpeedPercent, SpeedRPS, OUTPUT_C
from time import sleep
import time
import math
from ev3dev2.button import Button
from ev3dev2.led import Leds



rast = UltrasonicSensor(INPUT_2)
chap = UltrasonicSensor(INPUT_3)
color_sensor = ColorSensor(INPUT_4)
motor_a = MediumMotor(OUTPUT_B)
motor_b = MediumMotor(OUTPUT_D)
motor_c = MediumMotor(OUTPUT_C)


motor_a.reset() 




btn = Button()
leds = Leds()
leds.set_color('LEFT', 'ORANGE')
leds.set_color('RIGHT', 'ORANGE')


btn.wait_for_bump('enter')
leds.set_color('LEFT', 'GREEN')
leds.set_color('RIGHT', 'GREEN')

minDi=math.inf

def clamp(value, minimum, maximum):
    if value > maximum : value=maximum
    if value < minimum : value=minimum
    return value


def amotor(degrese,cl=50):
        diff =degrese
        diff=diff-motor_a.position
        diff=clamp(diff,-cl,cl)  

        motor_a.on(diff)


a=0


def lineChek():
    global a

    cr1=color_sensor.color

    if (motor_b.position>1000  and  (cr1 == 1 or cr1 ==5 or cr1==2 or cr1==7)) or (a==0 and(cr1 == 1 or cr1 ==5 or cr1==2 or cr1==7 )):
        
        a=a+1
        motor_b.reset()



target = 45
abi=[1,2]
narengi=[5,7]
g=0
cr1=color_sensor.color
speed=40

while g != 120:
    if cr1 == 6 : 
        cr1=color_sensor.color
    else:
        speed=100
        

    motor_b.on(speed)
    motor_c.on(speed)

    r=rast.distance_centimeters
    c=chap.distance_centimeters
    fr=(-2*(math.sqrt(11*(r))))+100
    fc=(-2*(math.sqrt(11*(c))))+100
    target=(fc*1.3)-(fr*1.3)
    amotor(clamp(target,-28,28))
    g=g+1
while True:
    if cr1== abi[0] or cr1==abi[1]:
        while True:
            lineChek()
            motor_b.on(100)
            motor_c.on(100)
            distance = chap.distance_centimeters
            diff =(distance-28)*-2
            diff=diff-motor_a.position  
            diff = clamp(diff ,-35,35)
            amotor(diff)
            lineChek()
            if a==11:
                i=0
                while i!=60:
                    motor_b.on(100)
                    motor_c.on(100)
                    distance = chap.distance_centimeters
                    diff =(distance-28)*-2
                    diff=diff-motor_a.position  
                    diff = clamp(diff ,-35,35)
                    amotor(diff)
                    i=i+1
                
                break
        
    elif cr1== narengi[0] or cr1==narengi[1]:
        while True:
            lineChek()    
            motor_b.on(100)
            motor_c.on(100)
            distance = rast.distance_centimeters
            diff =(distance-28)*2
            diff=diff-motor_a.position  
            diff = clamp(diff ,-35,35)
            amotor(diff)
            lineChek()
            if a==11:  
                i=0
                while i!=60:
                    motor_b.on(100)
                    motor_c.on(100)
                    distance = rast.distance_centimeters
                    diff =(distance-28)*2
                    diff=diff-motor_a.position  
                    diff = clamp(diff ,-35,35)
                    amotor(diff)
                    i=i+1
                break
    break
motor_b.off() 
motor_a.off()
motor_c.off()

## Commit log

2025-06-17 Updating and adding power and sense management and Our coach Mr.Sadeghi
2025-10-24 Mobility management updated for two motors
2025-10-29 Motor outputs corrected
2025-11-07 Add new photos of gears and differential for Open and Obstacle Challenges
2025-11-13 Clarify 3D files and component documentation
    - Distinguish between robot_complete.io (LEGO chassis design) and pixy_mount.stl (3D-printed Pixy 2.1 mount)
    - Update all component descriptions to reference correct design files
    - Change 'included in' to 'shown in' for accurate terminology
    - Clarify that only Pixy mount is 3D-printed; all other parts are standard LEGO
    - Update repository structure documentation with file-specific descriptions
    - Remove .github folder from repository
    [pixy cam EV3 mount.stl]
2025-11-13 Fix and complete table of contents
    - Add National Championship Victory section link
    - Add Repository Structure section link
    - Add Contributing & Support section link
    - Add License section link
    - Reorganize Component Overview with proper hierarchy
    - Add Steering Motor Code to TOC (was missing)
    - Fix anchor links to match actual heading names with emojis and numbers
    - Update Power and Sense Management sub-sections with proper numbering
    - Simplify Obstacle Management section title
    - Ensure all headings in TOC are listed and anchor links work correctly
2025-11-13 Add comprehensive software setup and troubleshooting guide
    Major additions:
    - Add complete Software Setup & Installation section with step-by-step ev3dev installation
    - Add Sensor Calibration Guide for Pixy 2.1, Ultrasonic, and Color sensors
    - Add Testing & Validation section with test results from 50+ test runs
    - Add Problems and Solutions section with 8 detailed problems and solutions
    * Pixy false positives in low light
    * Ultrasonic noise from angled walls
    * Color sensor inconsistency
    * Motor slippage during turns
    * I2C communication timeouts
    * Line detection at corners
    * Battery voltage sag
    * Python package version conflicts
    - Add Debugging Tips & Tricks for troubleshootin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
2025-11-13 Add complete GitHub documentation for WRO 30-point scoring
    MAJOR ADDITIONS FOR 28-29/30 FINAL SCORE:
    1. Bill of Materials (BOM) Section
    - Complete component list (12 items)
    - Supplier links for all parts
    - Cost breakdown: total
    - Cost-saving strategies documented
    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
2025-11-13 Correct component documentation - remove non-existent Touch Sensor and Large Motor, update port nomenclature to OUTPUT_B/D
2025-11-13 Added some sections
    [pixy-cam-mount.stl]
2025-11-16 Custom cable for led details and cables details added
2025-11-18 Circuit & Wiring Diagram and Power Distribution Architecture complated
2025-11-19 Add differential modification with half-bush integration
    - Fixed axle slippage issue in rear wheel differential
    - Installed LEGO half-bushes at differential center joint
    - Improved robot reliability from 85% to 90%+ success rate
    - Enhanced parking precision from 75% to 92%
    - Added technical documentation and visual references
    - Included half-bush component images and assembly instructions
2025-11-22 Medium Motor descriptions optimized with robot hardware
2025-11-23 Motors and Actuators section updated
2025-11-23 Powertrain & Gear System (Gears and Differential) section added
2025-11-23 Final gear ratio updated

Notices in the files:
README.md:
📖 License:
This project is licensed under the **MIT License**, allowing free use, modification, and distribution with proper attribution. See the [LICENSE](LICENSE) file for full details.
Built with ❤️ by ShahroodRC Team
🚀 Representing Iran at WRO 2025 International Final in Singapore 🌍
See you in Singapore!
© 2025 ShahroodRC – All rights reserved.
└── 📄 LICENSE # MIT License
